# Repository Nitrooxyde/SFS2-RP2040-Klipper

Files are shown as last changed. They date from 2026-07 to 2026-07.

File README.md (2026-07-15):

# BTT SFS 2.0 + RP2040‑Zero — Standalone USB Filament Sensor for Klipper







A **self‑contained, plug‑and‑play filament sensor module** for any Klipper printer:
a **BigTreeTech Smart Filament Sensor (SFS) 2.0** read by a **Waveshare RP2040‑Zero**
flashed as a standard **Klipper USB MCU**, both housed in a **one‑piece printed
receptacle**. One USB cable in, two native Klipper sensor objects out.

The SFS 2.0 exposes two signals — a **runout switch** (filament present / absent) and
a **motion encoder** (~1 pulse / 2.88 mm of filament travel). The RP2040‑Zero turns
both into first‑class Klipper objects:

- `[filament_switch_sensor sfs_switch]` → filament presence
- `[filament_motion_sensor sfs_motion]` → movement / no‑movement (clog, slip)

**Printed part also published on:**
[Printables](https://www.printables.com/model/1781579-btt-sfs-20-rp2040-zero-receptacle) ·
[Cults3D](https://cults3d.com/fr/mod%C3%A8le-3d/divers/standalone-usb-filament-sensor-for-klipper-btt-sfs-2-0-rp2040-zero-receptacl)

---

## Why a dedicated USB MCU for a filament sensor?

The usual way to wire an SFS is two signal lines back to the main board. Giving the
sensor **its own $3 microcontroller on USB** instead has real advantages:

- **Zero pins needed** on your main or toolhead board — useful when they're full,
  or when you don't want to run signal wires across the printer.
- **Board‑agnostic** — no board‑specific headers, voltage rails or pin mappings to
  figure out; the module brings its own MCU and its own 3.3 V, and works the same
  on every printer.
- **Plug‑and‑play** — one USB cable. Move the module between machines, or add it to
  a printer that was never wired for it.
- **Electrically self‑contained** — the SFS is powered from the Pico's 3V3 pin;
  no shared rails, no level‑shifting questions.
- **A single printed part** — sensor + MCU + mounting = one module on a 2020
  extrusion.

What you do with the two signals is up to your config — they are ordinary Klipper
sensor objects:

- **pause on runout** (`pause_on_runout: True` when you're ready),
- **clog / jam detection** — extruder commanded to move, encoder says nothing moves,
- **slip / under‑extrusion detection** — commanded‑vs‑wheel differential,
- **feed verification inside your own macros** — the motion state keeps updating
  even when the sensor is disabled (verified in Klipper source), which makes it a
  clean *“is filament actually moving?”* probe for any custom automation
  (multi‑material feeds, load/unload sequences, whatever you build).

---

## What's in this repo

| Path | Contents |
|---|---|
| [`docs/01-hardware.md`](docs/01-hardware.md) | SFS 2.0 + RP2040‑Zero specs, verified dimensions, BOM |
| [`docs/02-wiring.md`](docs/02-wiring.md) | SFS → Pico wiring, **the 3V3 rule**, pin map |
| [`docs/03-firmware-flashing.md`](docs/03-firmware-flashing.md) | Building & flashing Klipper on the RP2040‑Zero (Katapult) |
| [`docs/04-klipper-integration.md`](docs/04-klipper-integration.md) | `printer.cfg` blocks, safe bring‑up, usage |
| [`docs/05-cad-bracket.md`](docs/05-cad-bracket.md) | The printed receptacle: features, print settings, source |
| [`klipper/sfs.cfg`](klipper/sfs.cfg) | Ready‑to‑`[include]` Klipper config snippet |
| [`cad/SFS_Support_2020.stl`](cad/SFS_Support_2020.stl) | Print‑ready one‑piece receptacle (SFS 2.0 + RP2040‑Zero), definitive |
| [`cad/SFS20_Support_V4.FCStd`](cad/SFS20_Support_V4.FCStd) | FreeCAD source (direct modelling, not parametric — for adjustments) |
| [`firmware/`](firmware/) | Notes on the stock‑Klipper RP2040 build (no custom C) |

---

## Quick start (TL;DR)

1. **Print** `cad/SFS_Support_2020.stl` (ABS/ASA, 4 walls, 0.2 mm — see
   [docs/05](docs/05-cad-bracket.md)). Seat the pico in its cavity and **hot‑glue it
   at the four corners** — that's the retention method, and it doesn't move.
2. **Flash** the RP2040‑Zero with **stock Klipper, RP2040, USB, Katapult bootloader**
   ([docs/03](docs/03-firmware-flashing.md)).
3. **Wire** SFS → Pico: **VCC → 3V3 (never 5V)**, GND → GND, motion → **GP0**,
   switch → **GP1** ([docs/02](docs/02-wiring.md)).
4. **Add** the config below to `printer.cfg` (or copy `klipper/sfs.cfg` next to it
   and `[include sfs.cfg]`), fix the serial to *your* board, `FIRMWARE_RESTART`.

```ini
[mcu sfs]
serial: /dev/serial/by-id/usb-Klipper_rp2040_XXXXXXXXXXXXXXXX-if00

[filament_motion_sensor sfs_motion]
switch_pin: ^sfs:gpio0        # GREEN wire — motion encoder
detection_length: 2.88        # mm; SFS theoretical pulse pitch — tune at the bench
extruder: extruder
pause_on_runout: False        # bring-up safe: observe first, arm later

[filament_switch_sensor sfs_switch]
switch_pin: ^sfs:gpio1        # BLUE wire — runout switch
pause_on_runout: False
```

> ⚠️ **The two golden rules** (details in the docs):
> 1. **Power the SFS at 3.3 V.** The RP2040 is **not** 5 V‑tolerant (~3.8 V abs max).
>    5 V on the signal lines destroys the Pico.
> 2. **Keep the `^` pull‑ups.** The SFS outputs are open‑collector / switch‑to‑ground;
>    without an internal pull‑up they float.

---

## Placement

Anywhere on the filament path — that's the point of a self‑contained module. One
practical rule: **the closer to the extruder, the less slack** between the encoder
wheel and the drive gear, so the tighter `detection_length` can be and the earlier a
real clog or runout is flagged. And fit the **PTFE ID2/OD4 guide all the way into the
SFS bore on both ports** — without it, pushed filament buckles at the junction
(empirically confirmed; see [docs/01](docs/01-hardware.md)).

---

## Status

**Functional.** Built and running on a Voron 2.4: the receptacle prints and fits, the
RP2040‑Zero runs stock Klipper over USB (Katapult in place — no BOOT button needed for
reflash), and both sensor objects run in Klipper with the SFS powered at 3V3. The
definitive STL isn't claimed perfect — the pico is simply **hot‑glued at its four
corners** and doesn't move; a couple of optional refinements remain listed in
[docs/05](docs/05-cad-bracket.md).

Receptacle with the RP2040-Zero seated in its cavity

See [`CHANGELOG.md`](CHANGELOG.md) for the build history.

---

## Credits

- **Idea, design direction, build and real‑world testing:**
  [Nitrooxyde](https://github.com/Nitrooxyde)
- **Engineering legwork, CAD assistance and documentation:**
  [Claude](https://claude.com/claude-code) (Anthropic) — this project was
  designed and written in close collaboration with Claude Code, from the
  face‑by‑face CAD sessions to the docs you're reading.

## License

MIT — see [`LICENSE`](LICENSE). The BTT SFS 2.0 CAD model referenced in the docs is
BigTreeTech's own, distributed from their
[smart‑filament‑detection‑module](https://github.com/bigtreetech/smart-filament-detection-module)
repository under their terms.

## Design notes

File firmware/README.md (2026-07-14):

# firmware/

**There is no custom firmware in this project.** The RP2040‑Zero runs **stock
Klipper** compiled for the RP2040 as a **USB MCU**, with the **Katapult** bootloader
so reflashes need no BOOT button.

This folder exists only to hold the build recipe and (optionally) a captured
`.config` / binaries if you want to keep them versioned.

## Build recipe (menuconfig)

```
Micro-controller Architecture ....... Raspberry Pi RP2040
Bootloader offset ................... 16 KiB bootloader   (when using Katapult)
Communication interface ............. USB
```

```bash
cd ~/klipper
make menuconfig      # set the three options above
make clean && make   # -> out/klipper.uf2 / out/klipper.bin
```

Full flashing + Katapult + serial‑identification steps are in
[`../docs/03-firmware-flashing.md`](../docs/03-firmware-flashing.md).

## Reference board

- Serial: `usb-Klipper_rp2040_5303284738FB5E1C-if00`
- Katapult installed → future updates, no button, **two steps**: `make`, then
  `flashtool.py -d <klipper-serial> -r` (reboots the MCU into Katapult), then
  `flashtool.py -d <katapult-serial>` to flash — see
  [`../docs/03-firmware-flashing.md`](../docs/03-firmware-flashing.md).

> If you want a fully reproducible build, drop the Klipper `out/klipper.config`
> here and note the Klipper commit you built from.

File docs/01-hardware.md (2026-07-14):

# 01 — Hardware & specifications

## Bill of materials

| Qty | Part | Notes |
|-----|---|---|
| 1 | **BigTreeTech Smart Filament Sensor (SFS) 2.0** | Owned. Runout switch + motion encoder in one body. |
| 1 | **Waveshare RP2040‑Zero** | The USB MCU. 18 × 23.5 mm. **Not 5 V‑tolerant.** |
| 1 | Printed receptacle | `cad/REC_body_v1.stl` — houses both parts as one piece. |
| 2 | **PC4‑M6** pneumatic fittings | Supplied with the SFS; one at each filament port. |
| 1 | **PTFE tube ID2 / OD4** | **Mandatory** guide into the SFS bore (see below). |
| 2 | **M3×12 button‑head** screws | Fix the receptacle to the SFS mounting face (self‑tapping into the SFS). The receptacle's counterbores are sized for button heads; the M3×6 supplied by BTT are too short through the receptacle. |
| 2 | M3 screws + T‑nuts | Fix the receptacle's tab to a 2020 extrusion. |
| 1 | USB‑C cable | RP2040‑Zero → Raspberry Pi. |
| — | Dupont / JST‑to‑bare wiring | SFS's two 3‑pin leads → RP2040‑Zero pads. |

> The BTT SFS 2.0 ships with 3× M3×6 screws, 2× PC4‑M6, and a PTFE ID2/OD4/L30 tube.

---

## BTT SFS 2.0 — verified specifications

Cross‑checked three ways: live measurement of the official STEP in FreeCAD ==
BTT STEP == BTT manual (`SFS V2.0 …_20231123.pdf`).

### Mechanical
- **Body:** X 53.5 · Y 30.3 · Z 27.3 mm (BTT official: 53.1 × 30.3 × 27.3). ~36 g.
- **Mounting face:** the large 53 × 27 face (normal +Y; net measured face area
  ≈ 1054 mm² — less than 53 × 27 because of the cutouts in the face).
- **3× M3 self‑tapping holes** in that face (pilot Ø2.7, head counterbore ≈ Ø5,
  blind into the plastic — **no inserts**; BTT supplies 3× M3×6):

  | Hole | X (mm) | Z (mm) |
  |------|--------|--------|
  | H1 | −61.7 | +6.7 |
  | H2 | −37.0 | +6.7 |
  | H3 | −37.0 | −5.7 |

  Spacing (BTT manual): **24.7 mm × 12.4 mm**, L‑shaped pattern.

- **Filament path = X axis** (inline pass‑through, bidirectional, 1.75 mm).
  M6 ports at **both ends** (accept the 2× PC4‑M6). The two ports are **diagonally
  offset** (the filament routes around the encoder): Port A ≈ (Y 22.0, Z +6.3),
  Port B ≈ (Y 36.9, Z −6.3). Internal bore: Ø1.75 guide → Ø3.4 groove → Ø4.6/5.0
  PTFE seat.

### The PTFE guide is not optional (empirically confirmed)
On **push** (loading), any un‑guided gap between the fitting and the internal bore
becomes a **buckling point** — the filament escapes at the junction instead of
advancing. Adding the **PTFE ID2/OD4 tube all the way into the internal bore** (not
just seated in the PC4‑M6) unblocked pushing in real use. Invisible on **pull**
(unloading), so easy to under‑estimate at design time — **fit it on both ports.**

### Electrical — **read this before wiring**
- **Rated voltage: 3.3 V – 5 V ONLY.** The manual (p.5 *Specifications*; p.25
  *Caution*) is explicit: *“any higher voltage will cause damage.”*
  → **The SFS works officially at 3.3 V** — the "5V" label on BTT's wiring diagrams
  is because their host boards are STM32 (5 V rail + 5 V‑tolerant FT pins), **not**
  a power‑supply requirement.
- **Detection length:** 2.88 mm (theoretical) per encoder pulse.
- **Cable:** 100 cm Y‑cable — 1× **4‑pin** at the sensor → 2× **3‑pin** to the board.
- **Wire colours / signals:**

  | Colour | Signal | Notes |
  |--------|--------|-------|
  | **RED** | VCC | **Feed 3.3 V for the RP2040** (see wiring). |
  | **BLACK** | GND | |
  | **BLUE** | Switch / runout | Active‑low, **pull‑up required**. |
  | **GREEN** | Motion / encoder | Toggles ~1 pulse / 2.88 mm, **pull‑up required**. |

  Both outputs behave as **switch‑to‑ground / open‑drain** → an **MCU pull‑up is
  mandatory** (the RP2040's internal pull‑ups do the job, hence the `^` prefix in
  the Klipper config).

- **On‑board LEDs** (on the label face): red = empty; blue blinking = extrusion OK;
  blue solid / off = no movement. Detection is internal (no external optical window).

> **Not documented / confirm visually if you rebuild the cable:** the exact JST
> series of the 4‑pin (XH 2.54 vs PH 2.0) and the exact cable‑exit face/orientation.

### Official CAD / manual
BigTreeTech repo: [`bigtreetech/smart-filament-detection-module`](https://github.com/bigtreetech/smart-filament-detection-module)
- `/V2.0/CAD/SFS V2.0 Model.STEP` (the model used to design the receptacle)
- `/V2.0/CAD/SFS V2.0 Bracket for Hurakan.STEP` (BTT's own reference bracket)
- `/V2.0/STL`, `/V2.0/Manual/… _20231123.pdf`

The STEP model was kept locally at `Voron/SFS_V2_0/SFS V2.0 Model.STEP` (≈25 MB, not
bundled here to keep the repo lean).

---

## Waveshare RP2040‑Zero — specifications

- PCB **18 × 23.5 × ~1.6 mm**, **USB‑C** on a short edge.
- RP2040 + 2 MB flash, WS2812 (NeoPixel) LED + power LED, **BOOT/RESET** button.
- 9 castellated pads per side + through‑pads.
- **Logic 3.3 V. NOT 5 V‑tolerant** (RP2040 absolute max ≈ 3.8 V on any pin).
  This is *the* reason the SFS must be powered at 3.3 V here.

> The RP2040‑Zero STEP found online (`crides/kleeb`) has **11 mm male header pins**
> (a low‑profile keyboard variant) — those are a modelling artifact; the real Zero is
> ~1.6 mm bare. They were ignored when designing the receptacle.

### Third RP2040 on the rig — serial hygiene
This Pico is the **third** RP2040 Klipper MCU on the printer (after the **BTT Eddy**
and the **Fysetc PIS**). All three share VID:PID `1d50:614e` (Manufacturer "Klipper",
Product "rp2040"). **Always identify each board by its unique serial** before editing
a `[mcu …]` block — see [docs/03](03-firmware-flashing.md).

Known serials on the reference rig:
- Octopus Pro (STM32): `usb-Klipper_stm32f446xx_300025001350324E31333220-if00`
- BTT Eddy (RP2040 #1): `usb-Klipper_rp2040_504450593844A21C-if00`
- Fysetc PIS (RP2040 #2): `usb-Klipper_rp2040_E663B03597314E27-if00`
- **This SFS Pico (RP2040 #3): `usb-Klipper_rp2040_5303284738FB5E1C-if00`**

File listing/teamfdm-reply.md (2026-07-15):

# TeamFDM reply — thread #6534 "BTT SFS 2.0 with Leviathan mainboard"

> À poster en réponse au thread (compte user). Court : un apport tech sur leur
> problème + le repo en une ligne, comme alternative.
> https://www.teamfdm.com/forums/topic/6534-btt-sfs-20-with-leviathan-mainboard/

---

Small data point for future readers on the voltage side: the SFS 2.0 is
officially rated **3.3–5 V** (BTT manual, p.5 — the "5V" in their wiring
diagrams is just because the example boards are 5V-tolerant STM32s). Mine runs
fine on a clean, regulated 3.3 V — so if it doesn't work from a board's 3.3 V
pin, it's likely that rail sagging under load rather than the sensor needing 5 V.

Alternative approach if someone prefers to skip board pins entirely: I run mine
from a $3 RP2040-Zero flashed as a Klipper USB MCU (sensor powered by the pico's
3V3, one USB cable to the Pi). Write-up + printed mount here if it can help:
https://github.com/Nitrooxyde/BTT-SFS-2.0-RP2040-Zero-Klipper

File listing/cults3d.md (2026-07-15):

# Fiche Cults3D — prête à coller

> Fichiers à uploader : `cad/SFS_Support_2020.stl`
> Images : `docs/img/receptacle-pico-cavity.jpg`, `docs/img/receptacle-usbc-opening.jpg`
> **+ recommandé : 2–3 photos réelles** (pièce imprimée, module monté sur le 2020, câblage) — les photos réelles font ×3 sur les téléchargements.
> Catégorie : **Outil → Accessoires pour imprimante 3D**
> Prix : Gratuit (suggestion) · Licence : **« CC - Attribution »** dans leur menu (= CC BY, le « 4.0 » n'est pas affiché ; cohérent avec le repo MIT). Alternative si tu veux interdire la vente par d'autres : « CC - Attribution - Pas d'utilisation commerciale ».

---

## Titre (FR)

Capteur de filament USB autonome pour Klipper — support BTT SFS 2.0 + RP2040-Zero

## Titre (EN)

Standalone USB Filament Sensor for Klipper — BTT SFS 2.0 + RP2040-Zero receptacle

---

## Description (FR)

**Un module capteur de filament complet, autonome, en une seule pièce imprimée — un câble USB et c'est branché.**

Ce support monobloc loge un **BigTreeTech Smart Filament Sensor 2.0** et un **Waveshare RP2040-Zero** flashé en MCU Klipper USB. Le pico lit les deux signaux du SFS (présence + mouvement) et les expose à Klipper comme objets natifs :

- `filament_switch_sensor` → présence du filament (runout)
- `filament_motion_sensor` → mouvement réel (bourrage, glissement, sous-extrusion)

**Pourquoi un MCU dédié ?**
- **Zéro pin nécessaire** sur votre carte principale ou toolhead
- **Un seul câble USB** — pas de fils de signaux à tirer à travers l'imprimante
- **Plug-and-play** : déplaçable d'une machine à l'autre
- Électriquement autonome : le SFS est alimenté en 3,3 V par le pico

**Caractéristiques du support :**
- Fixation sur **profilé 2020** (patte avec 2 trous M3 pour écrous T)
- Se visse sur la face de montage du SFS (2× M3×12 tête bombée, lamages intégrés)
- Cavité pour le RP2040-Zero avec ouverture USB-C au contour du connecteur
- Accès aux boutons BOOT/RESET (trous oblongs 3×5 mm)
- 2 ports filament M6 pour raccords PC4-M6

**Assemblage :** le pico se colle à la **colle chaude aux 4 coins** dans sa cavité (simple, ferme, démontable). Passez les guides PTFE ID2/OD4 jusqu'au fond des ports du SFS (indispensable en poussée).

**⚠️ Câblage : alimentez le SFS en 3,3 V uniquement** (le RP2040 n'est pas tolérant au 5 V). Câblage complet, flash Klipper/Katapult et config prête à l'emploi sur le GitHub :
👉 **github.com/Nitrooxyde/BTT-SFS-2.0-RP2040-Zero-Klipper**

**Impression :** ABS/ASA (ou PETG), 0,2 mm, 4 périmètres, 30–40 % de remplissage. Supports uniquement sur les ouvertures selon l'orientation. STL vérifié étanche (59 488 facettes). Encombrement : 69 × 48 × 25 mm.

**BOM :** SFS 2.0 · RP2040-Zero · 2× M3×12 tête bombée · 2× M3 + écrous T · 2× PC4-M6 (fournis avec le SFS) · PTFE ID2/OD4 · câble USB-C · colle chaude.

Testé en réel sur une Voron 2.4.

---

## Description (EN)

**A complete, self-contained filament sensor module in a single printed part — one USB cable and you're wired.**

This one-piece receptacle houses a **BigTreeTech Smart Filament Sensor 2.0** and a **Waveshare RP2040-Zero** flashed as a Klipper USB MCU. The pico reads both SFS signals (presence + motion) and exposes them to Klipper as native objects:

- `filament_switch_sensor` → filament presence (runout)
- `filament_motion_sensor` → actual movement (clog, slip, under-extrusion)

**Why a dedicated MCU?**
- **Zero pins needed** on your main or toolhead board
- **One USB cable** — no signal wires across the printer
- **Plug-and-play**: move it between machines
- Electrically self-contained: the SFS runs on 3.3 V from the pico

**Receptacle features:**
- Mounts on a **2020 extrusion** (tab with 2× M3 holes for T-nuts)
- Screws onto the SFS mounting face (2× M3×12 button-head, counterbores included)
- RP2040-Zero cavity with a USB-C opening cut to the connector contour
- BOOT/RESET button access (3×5 mm oval holes)
- 2× M6 filament ports for PC4-M6 fittings

**Assembly:** hot-glue the pico at its **four corners** in the cavity (simple, firm, serviceable). Run the PTFE ID2/OD4 guides all the way into the SFS bore (mandatory when pushing filament).

**⚠️ Wiring: power the SFS at 3.3 V only** (the RP2040 is not 5 V-tolerant). Full wiring, Klipper/Katapult flashing and a ready-to-include config on GitHub:
👉 **github.com/Nitrooxyde/BTT-SFS-2.0-RP2040-Zero-Klipper**

**Printing:** ABS/ASA (or PETG), 0.2 mm, 4 walls, 30–40 % infill. Supports only on the openings depending on orientation. STL verified watertight (59,488 facets). Footprint: 69 × 48 × 25 mm.

**BOM:** SFS 2.0 · RP2040-Zero · 2× M3×12 button-head · 2× M3 + T-nuts · 2× PC4-M6 (supplied with the SFS) · PTFE ID2/OD4 · USB-C cable · hot glue.

Tested for real on a Voron 2.4.

---

## Tags

`klipper` `voron` `filament sensor` `runout sensor` `btt sfs` `rp2040` `smart filament sensor` `2020 extrusion` `3d printer accessory` `filament runout`

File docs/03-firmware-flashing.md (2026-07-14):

# 03 — Flashing Klipper on the RP2040‑Zero

There is **no custom firmware** here. The Pico runs **stock Klipper** as a USB MCU,
with the **Katapult** bootloader so future reflashes need no BOOT button.

## What is flashed on the reference board

- **Klipper**, target **Raspberry Pi RP2040**, communication **USB**.
- **Katapult** bootloader at the start of flash, Klipper offset by 16 KiB.
- Resulting serial: `usb-Klipper_rp2040_5303284738FB5E1C-if00`
  (yours will differ — read it from `/dev/serial/by-id/`).

## Build Klipper for the RP2040‑Zero

On the Pi (or wherever you build):

```bash
cd ~/klipper
make menuconfig
```

Set:
- **Micro-controller Architecture** → `Raspberry Pi RP2040`
- **Bootloader offset** → `16 KiB bootloader` *(if flashing on top of Katapult)*
- **Communication interface** → `USB`

Then:

```bash
make clean
make            # produces out/klipper.uf2 (and out/klipper.bin for Katapult)
```

## First flash (fresh board, UF2 over USB mass‑storage)

1. Hold **BOOT**, plug the USB‑C cable, release BOOT → the Pico mounts as a
   USB drive (`RPI-RP2`).
2. Copy the UF2 to it:
   - Katapult first (recommended): flash `katapult.uf2`, then flash Klipper via
     Katapult (below), **or**
   - Klipper directly (no Katapult): **rebuild with Bootloader offset =
     `No bootloader`**, then copy `out/klipper.uf2` onto `RPI-RP2`. (A 16 KiB‑offset
     build copied to a bare board will not boot — there is nothing at the start of
     flash.)

### Katapult (so you never need BOOT again)

**Step 1 — flash Katapult once (BOOT‑button method).**
Build Katapult for the RP2040 (`~/katapult`, `make menuconfig` → RP2040, communication
**USB**), then put the Pico in RPI‑RP2 mode (hold BOOT, plug USB) and copy
`out/katapult.uf2` onto the `RPI-RP2` drive. The board now enumerates as a Katapult
device: `/dev/serial/by-id/usb-katapult_rp2040_XXXX-if00`.

**Step 2 — build Klipper with the 16 KiB offset** (so it sits after Katapult):
`make menuconfig` → RP2040, **Bootloader offset = 16 KiB**, **USB** → `make`
(produces `out/klipper.bin`, which is what Katapult flashes — not the `.uf2`).

**Step 3 — flash Klipper through Katapult** (flashtool defaults to
`~/klipper/out/klipper.bin` wherever you run it from; use `-f` to point elsewhere):
```bash
python3 ~/katapult/scripts/flashtool.py -d /dev/serial/by-id/usb-katapult_rp2040_XXXX-if00
```
The board reboots into Klipper and now shows up as
`usb-Klipper_rp2040_XXXX-if00`.

**Later reflashes — no BOOT button, two steps.** With Klipper already running:

```bash
cd ~/klipper && make

# 1) ask the running Klipper MCU to reboot into Katapult (request only — exits)
python3 ~/katapult/scripts/flashtool.py \
    -d /dev/serial/by-id/usb-Klipper_rp2040_5303284738FB5E1C-if00 -r

# 2) the board re-enumerates as usb-katapult_rp2040_XXXX-if00 — flash through THAT
python3 ~/katapult/scripts/flashtool.py \
    -d /dev/serial/by-id/usb-katapult_rp2040_XXXX-if00
```

> `-r` only *requests* the bootloader and exits; over USB the board comes back under a
> **different serial** (`usb-katapult_…`), so the flash itself is always the second
> command. (One‑shot request+flash exists only for CAN devices, not USB.)

## Identify the board's serial (critical — 3rd RP2040 on the rig)

Three RP2040s share the same VID:PID. **Never** assume which `/dev/serial/by-id/`
entry is the SFS Pico.

```bash
# map every declared (uncommented) serial across all Klipper configs first
grep -rE '^\s*serial:' ~/printer_data/config/
```

To positively identify the SFS Pico when several RP2040s are plugged:

1. `ls /dev/serial/by-id/` — note the list.
2. Unplug the SFS Pico's USB‑C.
3. `ls /dev/serial/by-id/` again — the entry that **disappeared** is the SFS Pico.
4. Use that exact serial in `[mcu sfs]`.

> **Why this matters:** on this rig, blindly reusing an RP2040 serial once made
> Klipper open the same CDC‑ACM port twice (Eddy + a second block), causing
> `Resource temporarily unavailable` loops and cascading MCU shutdowns that looked
> like a hardware/probe fault. Map serials → devices *first*, edit `printer.cfg`
> *second*.

Known serials on the reference rig are listed in
[docs/01-hardware.md](01-hardware.md#third-rp2040-on-the-rig--serial-hygiene).

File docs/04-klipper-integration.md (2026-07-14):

# 04 — Klipper integration

## Config block

Add the following to `printer.cfg`, or drop [`klipper/sfs.cfg`](../klipper/sfs.cfg)
next to it and `[include sfs.cfg]`.

```ini
[mcu sfs]
serial: /dev/serial/by-id/usb-Klipper_rp2040_5303284738FB5E1C-if00   # <-- set to YOUR board

[filament_motion_sensor sfs_motion]
switch_pin: ^sfs:gpio0        # GREEN — motion encoder (open-collector → pull-up ^)
detection_length: 2.88        # mm; SFS theoretical pulse pitch. Tune at the bench.
extruder: extruder
pause_on_runout: False        # bring-up: observe, don't auto-pause yet

[filament_switch_sensor sfs_switch]
switch_pin: ^sfs:gpio1        # BLUE — runout switch (open-collector → pull-up ^)
pause_on_runout: False
```

Points to get right:
- **The `^` (internal pull‑up) is mandatory** on both pins — the SFS outputs are
  switch‑to‑ground. Drop it and the inputs float.
- **`sfs:` prefix** = the alias of the `[mcu sfs]` block. `gpio0`/`gpio1` are the
  RP2040 GP0/GP1 pads (see [docs/02](02-wiring.md)).
- **`detection_length`** starts at the theoretical 2.88 mm. Raise it if you get false
  runout triggers (a longer window tolerates more slack/jitter before flagging
  no‑movement); it is a Klipper *debounce distance*, not a physical measurement.

## How Klipper reads these

- `[filament_switch_sensor sfs_switch]` — simple presence: `filament_detected`
  true/false. Fires runout logic when it goes empty.
- `[filament_motion_sensor sfs_motion]` — **not an instantaneous measurement**. On
  each encoder pulse it sets a target = *current extruder position + `detection_length`*,
  then every **0.25 s** checks whether the extruder passed that target **without** a new
  pulse. If it did → no‑movement → runout event. So the signal is a **debounced proxy**:
  confirmation arrives within the next few mm of extrusion, not at the exact instant.
  **Mount the sensor close to the extruder** when you can: the less slack between the
  encoder wheel and the drive gear, the tighter `detection_length` can be and the
  earlier a real no‑movement condition is flagged.

> The motion sensor's `filament_detected` state updates **even when the sensor is
> `ENABLE=0`** (in Klipper's source, `RunoutHelper.note_filament_present()` records
> the state *before* the `sensor_enabled` gate — only runout/insert **event
> processing** is disabled). That is what makes `sfs_motion` a usable
> *“it slips vs it advances”* probe during manual feed jogs.
>
> **Two limits to know** (per Klipper's implementation):
> - The **no‑movement check is forward‑only**: it flags when the extruder position
>   passes *last pulse position + `detection_length`*. During a **retract/unload**
>   the position moves backwards and never passes the target, so `filament_detected`
>   will not go False from lack of wheel movement — for unload verification, watch the
>   **pulse‑driven transitions** (each encoder pulse re‑asserts presence) instead.
> - Moves must go **through the extruder** (`G1 E…` while the printer is in the
>   *Printing* idle state). `FORCE_MOVE` neither triggers the check nor updates the
>   tracked extruder position.

## Safe bring‑up, then arm

1. Deploy with **`pause_on_runout: False`** on both. Nothing auto‑pauses.
2. Optionally add a `RESPOND` echo to *see* transitions in Mainsail without side
   effects while you confirm wiring and polarity:

   ```ini
   [filament_switch_sensor sfs_switch]
   switch_pin: ^sfs:gpio1
   pause_on_runout: False
   runout_gcode:  RESPOND MSG="SFS switch: RUNOUT"
   insert_gcode:  RESPOND MSG="SFS switch: filament present"
   ```

3. Watch the objects live:

   ```
   QUERY_FILAMENT_SENSOR SENSOR=sfs_switch
   QUERY_FILAMENT_SENSOR SENSOR=sfs_motion
   SET_FILAMENT_SENSOR SENSOR=sfs_motion ENABLE=1
   ```

   Or in the Mainsail console / status panel.
4. When wiring, polarity and `detection_length` are validated, **arm** it by setting
   `pause_on_runout: True` — or point `runout_gcode` at your own macros instead of a
   raw pause.

## Deploy checklist (Voron / Pi hygiene)

- **Edit `printer.cfg` via Mainsail or `sed`/`cat` on the Pi — not SCP‑overwrite.**
- **Back up first**, then edit.
- **Confirm `print_stats.state == 'standby'`** before `FIRMWARE_RESTART`.
- Never restart the machine mid‑print to add the sensor.

## What to build on top

The two objects are ordinary Klipper sensors — use them for whatever your setup needs:

- **runout → pause** — the classic use (`pause_on_runout: True` once validated),
- **clog / jam detection** — extruder commanded to move, encoder reports no movement,
- **slip / under‑extrusion detection** — commanded‑vs‑wheel differential,
- **feed verification in custom macros** — `sfs_motion`'s state keeps updating even
  when the sensor is `ENABLE=0`, so any automation (load/unload sequences,
  multi‑material feeds, …) can query *“is filament actually moving?”* without arming
  runout side effects. Mind the two limits above: no‑movement detection is
  **forward‑only** (during retracts, watch pulse‑driven transitions instead), and
  only extruder‑driven moves count.

> **Note on metering:** the SFS does **not** count meters. Klipper accumulates nothing
> from it (the wheel is ~1 pulse / 2.88 mm and slips), so real consumption still comes
> from `print_stats.filament_used` (or a spool manager). The SFS's unique value is the
> *commanded‑vs‑wheel differential* → detect slip / under‑extrusion.

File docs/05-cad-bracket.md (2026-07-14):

# 05 — The printed receptacle

A **one‑piece receptacle** that holds the **SFS 2.0** and the **RP2040‑Zero** together
and mounts to a **2020 extrusion** — so the whole sensor module is a single printed
part with one USB cable leaving it.

- **Print file:** [`cad/REC_body_v1.stl`](../cad/REC_body_v1.stl)
  — binary STL, **63 536 facets**, watertight (FreeCAD `MeshPart` export, linear
  deviation 0.01 / angular 0.05; mesh vs BREP volume within ~0.01 %).
- **Source:** [`cad/SFS20_Support_V2.FCStd`](../cad/SFS20_Support_V2.FCStd)
  — object `REC_body_v1`.
- Approx. bounding box: **X ≈ 79 mm** (incl. the 2020 tab) · **Y ≈ 47 mm** ·
  **Z ≈ 25 mm**.

> Design note: this is the clean parametric reconstruction. An earlier
> patch‑on‑patch version (`SUP_bracket_v1`) was scrapped and the part was rebuilt
> from scratch, face by face, against the real SFS/RP2040 geometry.

## Features

- **RP2040‑Zero cavity** at the −X end, USB‑C exposed through an opening cut to the
  **real connector contour** (obround; the tight axis is the ~3.4 mm connector
  height — see *Known‑open items* below).
- **2× M6 filament ports** matching the SFS bore, for the PC4‑M6 fittings.
  → Run the **PTFE ID2/OD4** guide all the way into the SFS bore on both
  (see [docs/01](01-hardware.md)).
- **2× M3 mounting tunnels** through the SFS mount face — Ø3.4 clearance shaft with a
  **flat Ø6 counterbore** for M3×12 button‑head screws (button head = flat‑bottom
  counterbore, never a conical countersink), ~6 mm thread engagement into the SFS.
- **2× BOOT/RESET access holes**, **ovalised 3.0 × 5.0 mm**, aligned to the Pico's
  KEY1/KEY2 buttons.
- **4× PCB standoffs**, trimmed to seat exactly on the board's top face
  (**Y = 56.60 mm + 0.10 mm clearance**) — no bottoming‑out on the PCB.
- **Reinforced outer wall ≈ 3.45 mm** for rigidity.
- **2020 mounting tab** on the −X face: extended +20 mm in X, **2× M3 through‑holes**
  for T‑nut mounting to the extrusion.
- Front mouth aligned to a single plane with a small **R0.3 fillet** on the front
  contour edges.

## Suggested print settings

This is a functional structural bracket, so print it strong:

| Setting | Value |
|---|---|
| Material | **ABS or ASA** (matches the toolhead environment; PETG works too) |
| Layer height | 0.2 mm |
| Walls / perimeters | **4** (wall count is the real strength lever, not layer height) |
| Infill | 30–40 % |
| Supports | Only where the USB‑C / port / button openings overhang, depending on orientation |

> Orientation is not prescriptive — pick the face that puts the mounting tab and the
> filament ports on clean surfaces and minimises support inside the pico cavity.

## Known‑open items / optional refinements

The part is **functional**; a few optional refinements were deliberately left open:

- **Pico Y‑retention** — the cavity is open; the RP2040 is held by the wall + USB‑C,
  add a clip/lid if you want positive retention.
- **USB‑C opening clearance** — the truly tight axis is the **connector height**
  (~3.4 mm opening vs ~3.16 mm connector, ≈0.2 mm play); the long axis is already
  ~2× the connector width. If your cable's overmold binds, open the *height* axis
  slightly in the source (an earlier tweak widened the long axis, which changes
  nothing — see `CHANGELOG.md`, 07‑04).
- **−Y mouth flush lip** — a ~0.01 mm residual skin (1/20 of a layer, not sliced) was
  left because OCC refused a perfectly coincident cut; reconstruct the −Y face as a
  separate parametric frame if you want a geometric flush.
- Minor plane‑alignment nits (floor/ceiling ±10.728 vs ±10.7) — cosmetic.

## ⚠️ Print the up‑to‑date STL, from the right place
When rebuilding/exporting: the FreeCAD export on the headless server writes into the
**snap sandbox** (`~/snap/freecad/2337/…`), *not* the real home, and writing to the
home root is blocked by AppArmor. Export to `~/Desktop/…` (SCP‑accessible) and
**always re‑read the file on disk** (facet count / size / date) to prove the content
before printing — do not trust the "export succeeded" message alone. (A stale STL once
got printed for 1h40 this way.)

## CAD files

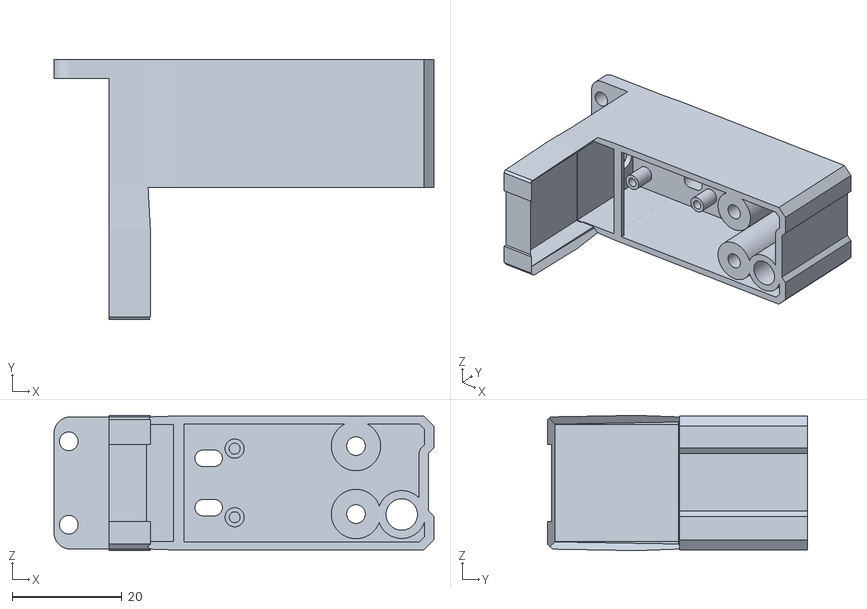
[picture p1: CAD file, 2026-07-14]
cad/REC_body_v1.stl
69.3 x 47.5 x 24.7

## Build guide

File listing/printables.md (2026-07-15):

# Printables listing — ready to paste

> Files to upload: `cad/SFS_Support_2020.stl`
> Images: `docs/img/receptacle-pico-cavity.jpg`, `docs/img/receptacle-usbc-opening.jpg`
> **+ recommended: 2–3 real photos** (printed part, module mounted on the 2020, wiring) — real photos massively boost downloads.
> Category: **3D Printers → Printer Accessories**
> License: pick **"Creative Commons — Attribution"** in the dropdown (= CC BY; the "4.0" version number isn't shown; consistent with the MIT repo). Alternative if you want to forbid others selling it: "Creative Commons — Attribution — NonCommercial".

---

## Title

Standalone USB Filament Sensor for Klipper — BTT SFS 2.0 + RP2040-Zero Receptacle

## Summary (short field)

One-piece receptacle for a BTT SFS 2.0 + RP2040-Zero running Klipper over USB. One cable in → native runout + motion sensors in Klipper. Zero pins needed on your boards. Mounts on 2020 extrusion.

---

## Description

**A complete, self-contained filament sensor module in a single printed part — one USB cable and you're wired.**

This receptacle houses a **BigTreeTech Smart Filament Sensor 2.0** and a **Waveshare RP2040-Zero** flashed as a standard Klipper USB MCU. The pico reads both SFS signals and exposes them to Klipper as native objects:

- `filament_switch_sensor` → filament presence (runout)
- `filament_motion_sensor` → actual movement (clog, slip, under-extrusion detection)

### Why a dedicated MCU?

- **Zero pins needed** on your main or toolhead board
- **One USB cable** — no signal wires across the printer
- **Plug-and-play** — move it between machines, or retrofit a printer never wired for it
- Electrically self-contained: the SFS runs on 3.3 V from the pico

### Receptacle features

- Mounts on a **2020 extrusion** (tab with 2× M3 holes for T-nuts)
- Screws onto the SFS mounting face — 2× M3×12 button-head, flat counterbores included
- RP2040-Zero cavity with a USB-C opening cut to the real connector contour
- BOOT/RESET button access holes (3×5 mm ovals)
- 2× M6 filament ports for the PC4-M6 fittings supplied with the SFS

### Assembly

1. Seat the pico in its cavity (USB-C through the end-wall opening) and **hot-glue it
   at the four corners** — simple, firm, and serviceable.
2. Screw the receptacle to the SFS with 2× M3×12 button-head.
3. Mount on the 2020 with M3 + T-nuts.
4. Run the **PTFE ID2/OD4 guides all the way into the SFS bore** on both ports —
   mandatory when pushing filament, otherwise it buckles at the junction.

### Wiring & Klipper config

**⚠️ Power the SFS at 3.3 V only** — the RP2040 is **not** 5 V-tolerant.
Motion → GP0, switch → GP1, internal pull-ups.

Full wiring guide, Klipper/Katapult flashing steps and a ready-to-include
`sfs.cfg` are on GitHub:
**https://github.com/Nitrooxyde/BTT-SFS-2.0-RP2040-Zero-Klipper**

### BOM

| Qty | Part |
|-----|---|
| 1 | BigTreeTech SFS 2.0 |
| 1 | Waveshare RP2040-Zero |
| 2 | M3×12 button-head screws |
| 2 | M3 screws + T-nuts (2020 mounting) |
| 2 | PC4-M6 fittings (supplied with the SFS) |
| — | PTFE tube ID2/OD4 |
| 1 | USB-C cable |
| — | Hot glue |

Tested for real on a Voron 2.4. STL verified watertight (59,488 facets).
Footprint: 69 × 48 × 25 mm.

---

## Print settings (structured fields)

- **Printer:** any (designed on a Voron 2.4)
- **Nozzle:** 0.4 mm
- **Layer height:** 0.2 mm
- **Material:** ABS / ASA (PETG works)
- **Perimeters/walls:** 4
- **Infill:** 30–40 %
- **Supports:** only on the USB-C / port / button openings, depending on orientation
- **Brim:** optional

## Tags

klipper, voron, filament-sensor, runout-sensor, btt-sfs, rp2040, smart-filament-sensor, 2020-extrusion, printer-accessory, filament-runout

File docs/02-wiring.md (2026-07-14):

# 02 — Wiring SFS 2.0 → RP2040‑Zero

## ⚠️ Two rules that protect the hardware

1. **VCC = 3.3 V. Never 5 V.**
   The RP2040 is not 5 V‑tolerant (abs max ≈ 3.8 V). The SFS is rated 3.3–5 V and
   works fine at 3.3 V, so powering it from the Pico's **3V3** pin caps every signal
   at 3.3 V → **safe regardless of the output topology**. That matters because the
   topology is not officially documented: if the outputs turn out to be push‑pull (or
   internally pulled up to VCC), powering at 5 V puts 5 V on the signal lines and
   **destroys the Pico's GPIO**. At 3.3 V nothing on the module can exceed 3.3 V.
2. **Internal pull‑ups on both signal pins** (`^` in Klipper).
   The SFS outputs are open‑collector / switch‑to‑ground. Without a pull‑up they
   float and read garbage.

---

## Pin map (decided for this build)

| SFS wire | Signal | → RP2040‑Zero pin | Klipper pin |
|---|---|---|---|
| RED | VCC | **3V3** (⚠ not 5V/VBUS) | — |
| BLACK | GND | **GND** | — |
| GREEN | Motion / encoder | **GP0** | `^sfs:gpio0` |
| BLUE | Switch / runout | **GP1** | `^sfs:gpio1` |

> GP0 / GP1 are the RP2040 UART0 pins, but the Pico runs as a **USB** MCU here, so
> UART0 is free — they are used purely as digital inputs with pull‑up.

```
   BTT SFS 2.0                        RP2040-Zero (USB)
 ┌──────────────┐                    ┌───────────────────┐
 │  motion  ────┼── GREEN ──────────►│ GP0  (^sfs:gpio0) │
 │  switch  ────┼── BLUE  ──────────►│ GP1  (^sfs:gpio1) │
 │  VCC     ────┼── RED   ──────────►│ 3V3  (! NOT 5V)   │
 │  GND     ────┼── BLACK ──────────►│ GND               │
 └──────────────┘                    │ USB-C ──► to Pi   │
                                     └───────────────────┘
```

The SFS's Y‑cable ends in **two 3‑pin** connectors (motion group and switch group),
each carrying its signal + a VCC + a GND. You only need **one** VCC and **one** GND to
the Pico; tie the two grounds together and the two VCCs together at 3V3.

---

## Bring‑up safety procedure (recommended)

Do this **before** trusting the signals — especially important because the RP2040 is
not 5 V‑tolerant:

1. **Power only** first: RED → 3V3, BLACK → GND. Leave GREEN/BLUE **unplugged**.
2. If you are unsure whether the SFS outputs are truly open‑collector, measure
   **output → GND** with a multimeter while powered:
   - ≈ 0 V / floating = open‑collector → **safe to connect** to the Pico.
   - ≈ VCC (push‑pull) = only safe because VCC is 3.3 V; would be fatal at 5 V.
3. Connect GREEN → GP0, BLUE → GP1.
4. Bring the sensor up in Klipper with `pause_on_runout: False` and just watch the
   state in Mainsail (see [docs/04](04-klipper-integration.md)) before arming
   any auto‑pause.

> **Cross‑check the wire colours against your actual cable** — colour conventions can
> vary between SFS batches. The signal *function* (open‑collector switch to GND, one
> for presence, one for motion) is what matters; map whichever wire is which on your
> unit.

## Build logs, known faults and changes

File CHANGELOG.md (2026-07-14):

# Changelog / build history

Chronology of how the SFS 2.0 + RP2040‑Zero USB filament sensor came together
(reference build: Voron 2.4, Raspberry Pi host).

## 2026‑07‑02 — Decision & scope
- Chose to read the **BTT SFS 2.0** with a dedicated **RP2040‑Zero flashed as a
  Klipper USB MCU** — a self‑contained, plug‑and‑play sensor module instead of wiring
  the two signals back to the main board. Two signals →
  `[filament_motion_sensor]` (clog/slip) + `[filament_switch_sensor]` (presence).
- Imported the official **SFS V2.0 Model.STEP** and the RP2040‑Zero model in FreeCAD.
  Cross‑verified SFS dimensions three ways (live measurement == STEP == manual).

## 2026‑07‑02 → 07‑03 — Receptacle CAD
- First bracket attempt (boolean patch‑on‑patch) was **rejected** and the part
  **rebuilt from scratch parametrically**, face by face, as `REC_body_v1` in
  `SFS20_Support_V2.FCStd`.
- Built up: pico cavity, USB‑C opening (real connector contour), 2× M6 filament ports,
  2× M3 mounting tunnels (Ø6 flat counterbore for M3×12 button‑head), 2× BOOT/RESET
  access holes, 4× PCB standoffs, mouth alignment + R0.3 front fillet.

## 2026‑07‑03 — STL exports
- `REC_body_v2.stl` (64 160 facets) exported.
- Later superseded by the re‑exported `REC_body_v1.stl` (see 07‑04).

## 2026‑07‑04 — Firmware, wiring decision, refinements
- **SFS spec verified from the official manual (PDF):** rated **3.3–5 V**, detection
  length **2.88 mm**. Conclusion: power the SFS at **3.3 V** for the (non‑5 V‑tolerant)
  RP2040.
- **Pin mapping decided:** motion → **GP0**, switch → **GP1**, pull‑ups on both.
- **RP2040‑Zero flashed** stock Klipper USB + Katapult →
  serial `usb-Klipper_rp2040_5303284738FB5E1C-if00`. Re‑tested OK.
- Receptacle refined: M3 tunnels' counterbores corrected, outer wall reinforced to
  ~3.45 mm, BOOT/RESET holes ovalised 3.0 × 5.0, PCB standoffs re‑trimmed to seat on
  the board face (Y 56.60 + 0.10 clearance), **2020 mounting tab** added.
- `printer.cfg` bring‑up block prepared (safe mode, `pause_on_runout: False`).
- **`REC_body_v1.stl` re‑exported** (63 536 facets, watertight) — the current print
  file.
- USB‑C opening widened by 0.3 mm (commit `elargir_usbc_+0.3`); later noted the
  *tight* axis is the ~3.4 mm connector‑height axis, not the one widened.

## 2026‑07‑05 — Deployed
- **Sensor module deployed on the reference printer at VCC 3.3 V, both sensor objects
  enabled in Klipper.**
- `sfs_motion` confirmed as the *"advances vs slips"* discriminator during manual
  load/unload jogs (its motion state updates even when the sensor is `ENABLE=0`).
- Confirmed empirically: **PTFE ID2/OD4 guide into the SFS bore is mandatory** on push
  (without it the filament buckles at the junction).

## 2026‑07‑15 — This repo
- Consolidated hardware, wiring, firmware, Klipper integration and CAD into a
  standalone, documented repository. Bracket bundled as print‑ready STL + FreeCAD
  source; Klipper config as a ready‑to‑include snippet.
- Documentation reframed: the module is a **generic standalone USB filament sensor** —
  application‑specific context from the reference printer (multi‑material feed
  experiments) removed from the docs; what you build on the two signals is up to
  your config.

---

### Notes on state
- The receptacle is **functional**; the FreeCAD source (`SFS20_Support_V2.FCStd`) and
  the print‑ready STL are both in `cad/`.
- The config to use is [`klipper/sfs.cfg`](klipper/sfs.cfg) — adapt the serial to your
  board.

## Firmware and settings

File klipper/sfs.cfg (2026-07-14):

# =============================================================================
#  BTT SFS 2.0 + RP2040-Zero  —  standalone USB filament sensor
#  Include from printer.cfg:   [include sfs.cfg]
#  Docs: ../docs/04-klipper-integration.md
# =============================================================================
#
#  BEFORE USE:
#   1) Set the serial below to YOUR board (see: ls /dev/serial/by-id/).
#      Three RP2040s share the same VID:PID on this rig — unplug this Pico
#      and see which /dev/serial/by-id entry disappears to identify it.
#   2) Power the SFS at 3.3 V (the RP2040 is NOT 5 V-tolerant).
#   3) Keep the ^ pull-ups (SFS outputs are open-collector / switch-to-ground).
#   4) Bring up with pause_on_runout: False, confirm in Mainsail, then arm.
# =============================================================================

[mcu sfs]
serial: /dev/serial/by-id/usb-Klipper_rp2040_5303284738FB5E1C-if00

# --- Motion / encoder (GREEN wire -> GP0) : clog / slip / no-movement ---------
[filament_motion_sensor sfs_motion]
switch_pin: ^sfs:gpio0
detection_length: 2.88          # mm, SFS theoretical pulse pitch; raise if false triggers
extruder: extruder
pause_on_runout: False
# runout_gcode:  RESPOND MSG="SFS motion: NO MOVEMENT"

# --- Switch / runout (BLUE wire -> GP1) : filament presence ------------------
[filament_switch_sensor sfs_switch]
switch_pin: ^sfs:gpio1
pause_on_runout: False
# runout_gcode:  RESPOND MSG="SFS switch: RUNOUT"
# insert_gcode:  RESPOND MSG="SFS switch: filament present"

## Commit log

2026-07-14 Initial commit — SFS 2.0 + RP2040-Zero post-Y filament sensor for Klipper
    Consolidates the full project into a documented repo:
    - README overview + quick start + bigger-picture (multi-lane / endless-spool)
    - docs/: hardware & verified specs, wiring (3V3 rule), Klipper flashing (Katapult),
    Klipper integration (mcu + motion/switch sensors), CAD receptacle
    - klipper/sfs.cfg: ready-to-include config snippet
    - cad/: print-ready REC_body_v1.stl (63536 facets, watertight) + FreeCAD source
    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
    [REC_body_v1.stl, sfs.cfg]
2026-07-14 docs/03: tighten the Katapult flashing procedure
    - Split into clear steps: flash Katapult (BOOT) -> build Klipper with 16KiB
    offset -> flash klipper.bin via flashtool.py
    - Drop the misleading flash_can.py line (this is a USB board, not CAN)
    - Document buttonless reflash: point flashtool at the Klipper serial with -r
2026-07-14 Reframe as a standalone generic USB filament sensor + fix review findings
    Reframing (the point of this commit):
    - The module is a self-contained, generic USB filament sensor for Klipper —
    runout, clog, slip, feed verification for ANY setup. Removed all framing
    that presented it as a component of a specific multi-material architecture
    (README bigger-picture section, CHANGELOG roadmap wording, docs/04 role
    section, placement naming in docs/05 and sfs.cfg).
    Technical fixes (from adversarial review, 3 lenses / 25 findings):
    - docs/03 + firmware/: Katapult USB reflash is TWO steps (-r requests the
    bootloader and exits; flash via the katapult serial that re-enumerates);
    UF2-direct p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
    [sfs.cfg]
2026-07-15 Repo renamed to BTT-SFS-2.0-RP2040-Zero-Klipper; update links; TeamFDM reply draft
    - Listing files now point to the new repo URL (old URL redirects)
    - listing/teamfdm-reply.md: ready-to-post reply for thread #6534
2026-07-15 README: credits — Nitrooxyde (idea, design, build, testing) + Claude (engineering, CAD, docs)
2026-07-15 teamfdm reply: minimal — one voltage data point + repo link as alternative
